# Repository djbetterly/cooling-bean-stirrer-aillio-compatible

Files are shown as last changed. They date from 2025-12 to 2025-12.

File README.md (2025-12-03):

# R1/R2 Cooling Bowl Stirrer (Aillio-Compatible)

<p align="center">
  
  
  
  <a href="https://github.com/djbetterly/cooling-bean-stirrer-aillio-compatible/releases">
    
  </a>
  <a href="https://github.com/djbetterly/cooling-bean-stirrer-aillio-compatible">
    
  </a>
</p>

### Open Hardware Release • Designed by Dustin Betterly



This **cooling bowl stirrer** is an open-hardware accessory **designed for compatibility with the Aillio R1 and R2 cooling bowls**.
It is **not affiliated with or endorsed by Aillio**.

Its purpose is simple: **speed up the cooling cycle and help remove any chaff that didn’t escape during roasting.**

By actively agitating the beans during cooling, the stirrer:

* Accelerates heat dissipation
* Improves airflow through the bean mass
* Breaks up clumps for more uniform cooling
* Helps eject additional trapped chaff
* Reduces total cooling time compared to passive airflow alone

**This tool is for post-roast cooling only.
It is NOT designed for use inside the roasting drum.**

---

## ✨ Features

* Rapid bean agitation for faster, more uniform cooling
* Helps remove residual chaff that didn’t exit the drum
* High-temperature stir paddle (PA6-CF recommended)
* Wear-friendly PTFE washer system
* Completely printable housing, paddle, and thumb screws
* Tested for safe use with hot roasted beans
* Open hardware — remix, improve, share

---

## 📦 Repository Contents

### /STL

* 3D Print - Bean Stirrer.stl
* 3D Print - Bottom Wear Plate.stl
* 3D Print - Top Wear Plate.stl
* 3D Print Axel Hub.stl
* 3D Print M5 Thumb Screw.stl
* 3D Print Motor Body Base.stl
* 3D Print Motor Body Wire Cover.stl
* Motor Body Cover.stl

### /docs

* bean_stir_manual.pdf
* Exploded_View.pdf

### /images

* hero_render.png

Other:

* README.md
* LICENSE (CC BY-NC 4.0)

---

## 🧰 Bill of Materials (BOM)

See:

* docs/Exploded_View.pdf

Key hardware:

* 80 mm stainless square rod (cut to length)
* PTFE shoulder washers
* Heat-set inserts
* Assorted M3/M5 fasteners
* 12 V DC motor (reverse-rotation supported)

---

## 🛠 Material Recommendations

| Part | Material | Brand | Notes |
| --- | --- | --- | --- |
| Stir Paddle | PA6-CF | Polymaker Fiberon | High heat deflection so hot beans won’t deform the paddle |
| Wear Plates | PA6-CF | Polymaker Fiberon | Low friction and heat resistant |
| Housing/Covers | PLA-CF | Bambu Labs | Rigid, stable, clean finish |
| Thumb Screws | PLA-CF | Bambu Labs | Strong and easy to bond to steel screws |

---

## 🪚 Cutting the Square Rod (80 mm)

The stainless square bar must be cut to **80 mm** final length.

Steps:

1. Mark 80 mm with calipers or a precise ruler
2. Cut using a hacksaw, bandsaw, or cutoff wheel
3. Deburr both ends with a file or sandpaper
4. Verify a smooth sliding fit into the printed hubs
5. Target tolerance: **80 ± 0.25 mm**

---

## 🖨 Printing Guidance

### Stir Paddle (PA6-CF)

* Print upside-down
* Supports: build plate only
* Add a pause to insert the embedded nut
* Optional: resin coat + sand for smoother finish

### Thumb Screws

* Pause print to insert the M5 screw
* Secure using resin or cyanoacrylate

---

## 🔧 Assembly Overview

See:

* docs/Aillio_Stirrer_Manual_FINAL_NEW_EXPLODED.pdf
* docs/Exploded_View.pdf

General notes:

* Center the stir paddle on the cooling bowl’s middle pin
* Do **not** overtighten the paddle screw — it must rotate freely
* Leave motor screws slightly loose during alignment
* Apply blue Loctite after the final position is confirmed

---

## ⚡ Motor & Power

* Uses a 12 V DC motor
* If the paddle spins backward → swap + and – wires
* Recommended power supply: **12 V / 2 A**

---

## 🛡 License — CC BY-NC 4.0

This project is released under a **Creative Commons Attribution-NonCommercial 4.0 International License**.

You may:

* Print and remix for personal use
* Share non-commercially
* Must credit: **Dustin Betterly**

You may NOT:

* Sell the files
* Sell printed parts or kits
* Use commercially without permission

Full license text:
[https://creativecommons.org/licenses/by-nc/4.0/](https://creativecommons.org/licenses/by-nc/4.0/)

---

## 🙌 Credits

**Design & documentation:**
Dustin Betterly

**Render:**
images/hero_render.png

---

## 🗂 Version History

### v1.0 — Initial Public Release

* Finalized STL files
* Updated exploded view
* Complete build manual
* Updated naming for trademark safety
* CC BY-NC license applied

> If you build it, share your results!
> Pull requests, improvements, and remixes are welcome (non-commercial only).

---

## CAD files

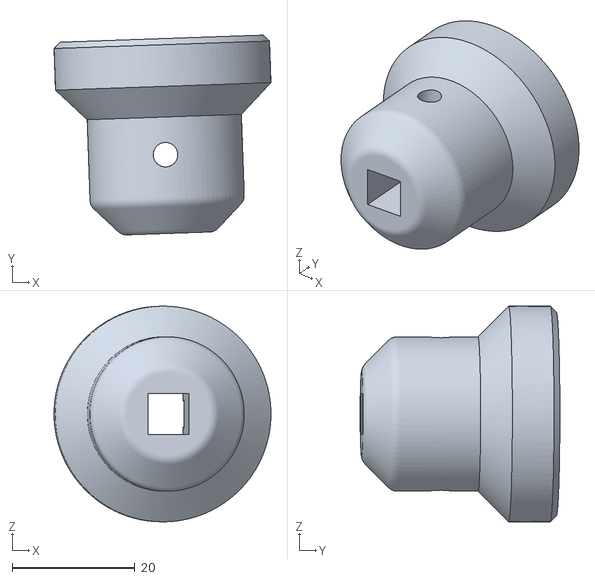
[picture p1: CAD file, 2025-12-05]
STL/3D Print Axel Hub.stl
35.4 x 32.6 x 35.2

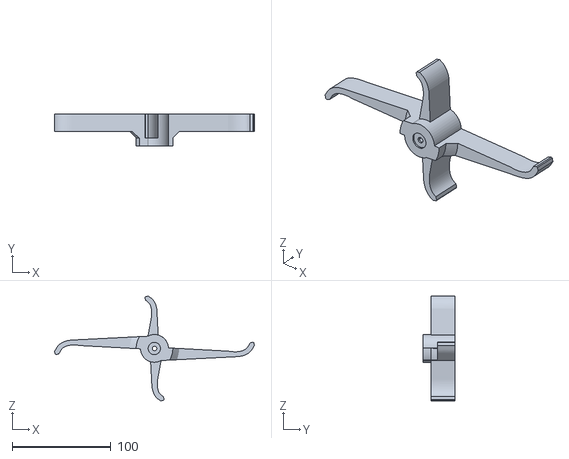
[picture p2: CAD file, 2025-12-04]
STL/3D Print - Bean Stirrer.stl
202.5 x 32.7 x 106.1

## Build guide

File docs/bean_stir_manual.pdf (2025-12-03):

## Designed by Dustin Betterly

### Includes Build Notes, License, and Exploded Technical Drawing

# R1/R2 Bean Stirrer

## (Aillio Compatible)

# Open Hardware Release Manual

# Disclaimer

This project is provided as open hardware for community use. No warranty of any kind is provided. Use, modification, and assembly of this project are at your own risk. By using these files, you agree that: -You are responsible for safe printing, assembly, and operation. - You assume all risks associated with mechanical, electrical, or thermal failure. - The designer is not liable for damages, injury, or loss. These notes provide high-level guidance only and are not step-by-step instructions.

# License - CC BY-NC 4.0

This project is released under the Creative Commons Attribution-NonCommercial 4.0 License. You may: - Print, remix, and adapt the files. - Share them for non-commercial use. - Must credit the original designer: Dustin Betterly. You may NOT: - Sell the files or derivatives. - Sell printed parts or kits. - Use

### this design commercially without permission. Full license: https://creativecommons.org/licenses/by-nc/4.0/

# Build Notes

# 3D Printed Parts & Materials

(Your original table with brands, links, and materials should remain exactly as-is below this text.)

The materials were selected to balance durability, printability, and performance in a high-heat environment.

## - Polymaker Fiberon PA6-CF was chosen for the stirrer paddle and wear plates because of its high heat deflection temperature, ensuring that hot roasted beans won’t soften

or deform the stirrer.

## - Bambu Labs PLA-CF was used for structural parts such as the motor housing and

covers due to its stiffness, clean surface finish, and dimensional stability.

These combinations provide excellent strength and durability while maintaining reliability around elevated temperatures.

Motor Body | Bambu Labs PLA-CF
Bean Stirrer | Polymaker Fiberon PA6-CF (https://www.amazon.com/dp/B0D4QDTHPQ?ref_=ppx_hzsearch_conn_dt_b_fed_asin_title_1&th=1)
Axel Hub | Bambu Labs PLA-CF
Top Wear Plate | Polymaker Fiberon PA6-CF (https://www.amazon.com/dp/B0D4QDTHPQ?ref_=ppx_hzsearch_conn_dt_b_fed_asin_title_1&th=1)
Bottom Wear Plate | Polymaker Fiberon PA6-CF (https://www.amazon.com/dp/B0D4QDTHPQ?ref_=ppx_hzsearch_conn_dt_b_fed_asin_title_1&th=1)
M5 Thumb Screw | Bambu Labs PLA-CF
Motor Body Cover | Bambu Labs PLA-CF
Motor Body Wire Cover | Bambu Labs PLA-CF

These notes cover recommended materials, printing considerations, and general guidance for assembling and using the Aillio Bean Stirrer. This is not a step-by-step assembly guide. Use the exploded view drawing for part orientation and placement.

# Part Preparation

## Stir Paddle

After printing the paddle, I applied three coats of art resin, then sanded and polished the surface. This step is optional, but it improves smoothness and overall durability.

## Be careful not to let resin enter:

## - the bottom screw hole

## - the square axle hole

Both must remain clean for proper assembly.

## M5 Thumb Screws

## After printing the thumb screw bodies:

1. Thread the M5 screw into the printed body as far as it will go.
2. Secure it using either superglue or a small amount of art resin in the cavity.

Resin creates a permanent bond once cured.

## Cutting the Square Rod (Stainless Bar, Item 17)

The stainless steel square rod (Item 17 in the exploded view) must be cut to a final working length of 80 mm before assembly.

## Recommended cutting steps:

1. Measure and mark 80 mm from one end using calipers or a precision ruler.

## 2. Use a fine-tooth hacksaw, rotary tool with cutoff wheel, or metal bandsaw to make the

cut.

3. Deburr both ends with a file or sandpaper (120–220 grit) to remove sharp edges.
4. Ensure the rod slides cleanly into the printed hub and coupler without binding.

## 5. Confirm final length is 80 ± 0.25 mm (slight variance is acceptable)

## Printing the Stir Paddle (Embedded Nut)

## The paddle includes an embedded locking nut. For best results:

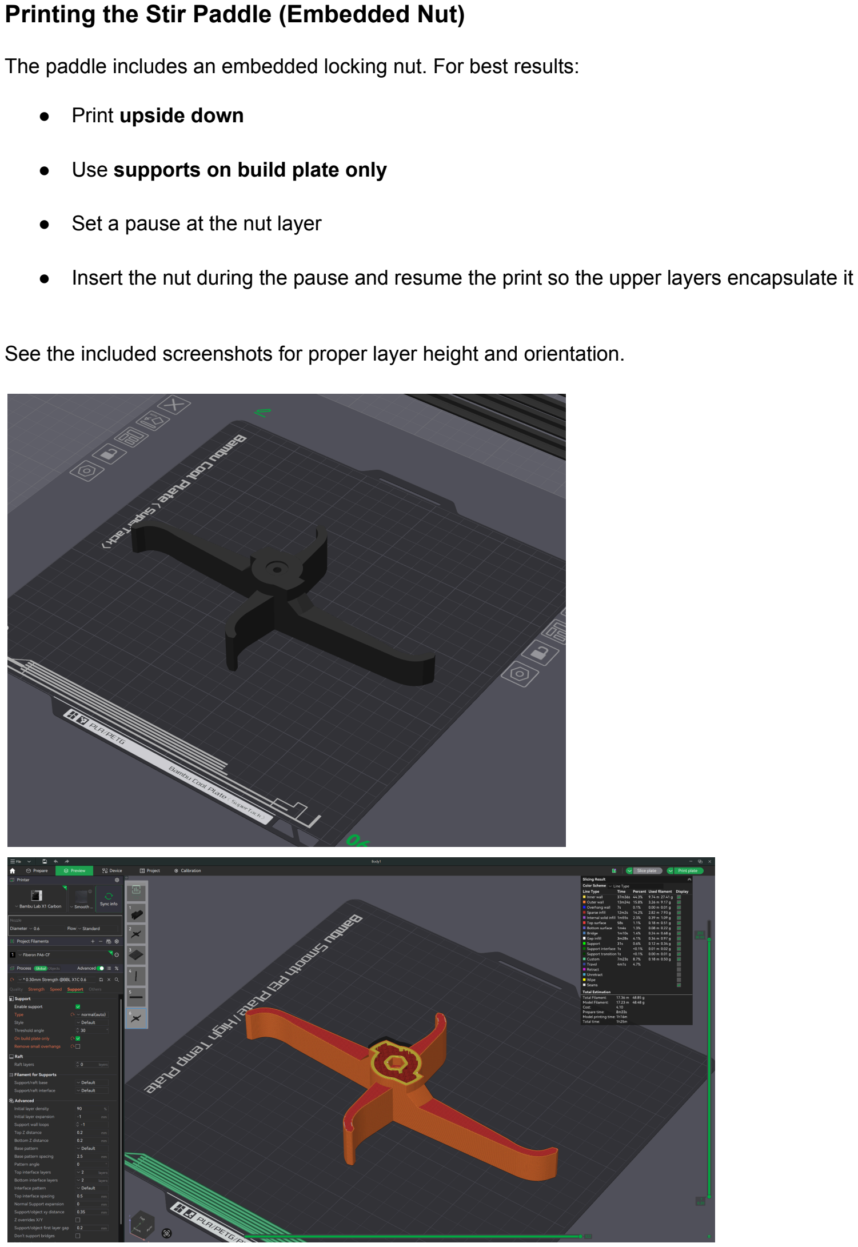
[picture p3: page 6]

## - Print upside down

## - Use supports on build plate only

## - Set a pause at the nut layer

## - Insert the nut during the pause and resume the print so the upper layers encapsulate it

See the included screenshots for proper layer height and orientation.

# Assembly Guidance

Use the exploded view drawing to identify part placement and orientation.

## When mounting the motor:

## - Leave the motor screws slightly loose during initial alignment—this helps reduce

vibration.

## - Once aligned, apply a small amount of blue Loctite to prevent the screws from backing

out during use.

## The goal is “secure but not stressed.”

# Installing the Stir Paddle in the Aillio Basket

The stirrer assembly includes several components. Carefully reference the exploded view to confirm the correct stack and alignment.

There is a small hole at the very center of the basket—this is where the stir bar must align. Do not overtighten the screw: the stir bar should rotate freely but without wobble.

A close-up diagram is included to assist with visual orientation.

# Wiring & Power Supply

The motor referenced in the BOM/exploded view is a reverse-rotation motor.

## If the paddle spins in the wrong direction:

- Reverse the positive and negative wires at the barrel connector.
This is safe and supported by the motor’s specifications.

A standard 12V / 2A power supply works well. (https://www.amazon.com/dp/B0D269PYK9?ref_=ppx_hzsearch_conn_dt_b_fed_asin_title_2)
Ensure the barrel connector matches both the motor and your chosen receptacle.

# Parts Wear & Long-Term Use

## This design has been tested for several weeks, but long-term wear may vary depending on

materials, roasting temperature, and usage frequency.

The white PTFE washers are designed to be the sacrificial wear components.
With the recommended materials, overall longevity should be good, though individual results may vary.

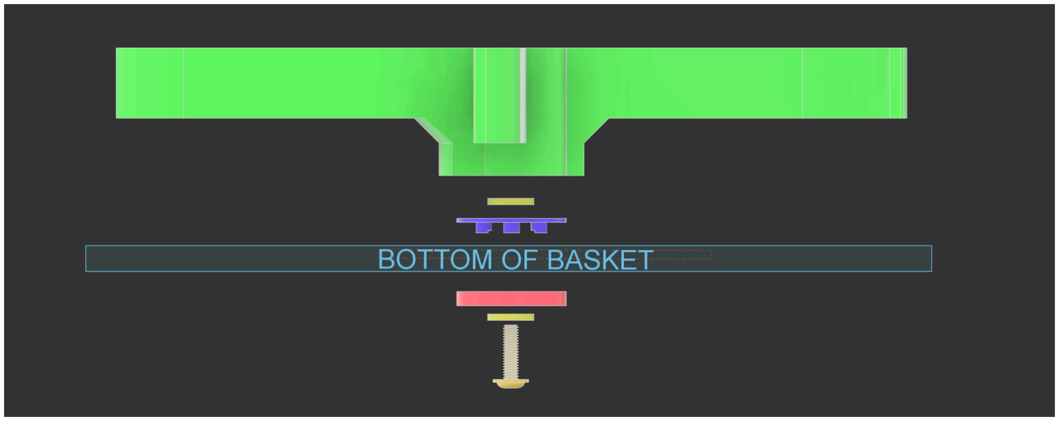
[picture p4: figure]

## Parts List

Item | Qty | Part Number | Material 1 | 1 | 3D Print - Bean

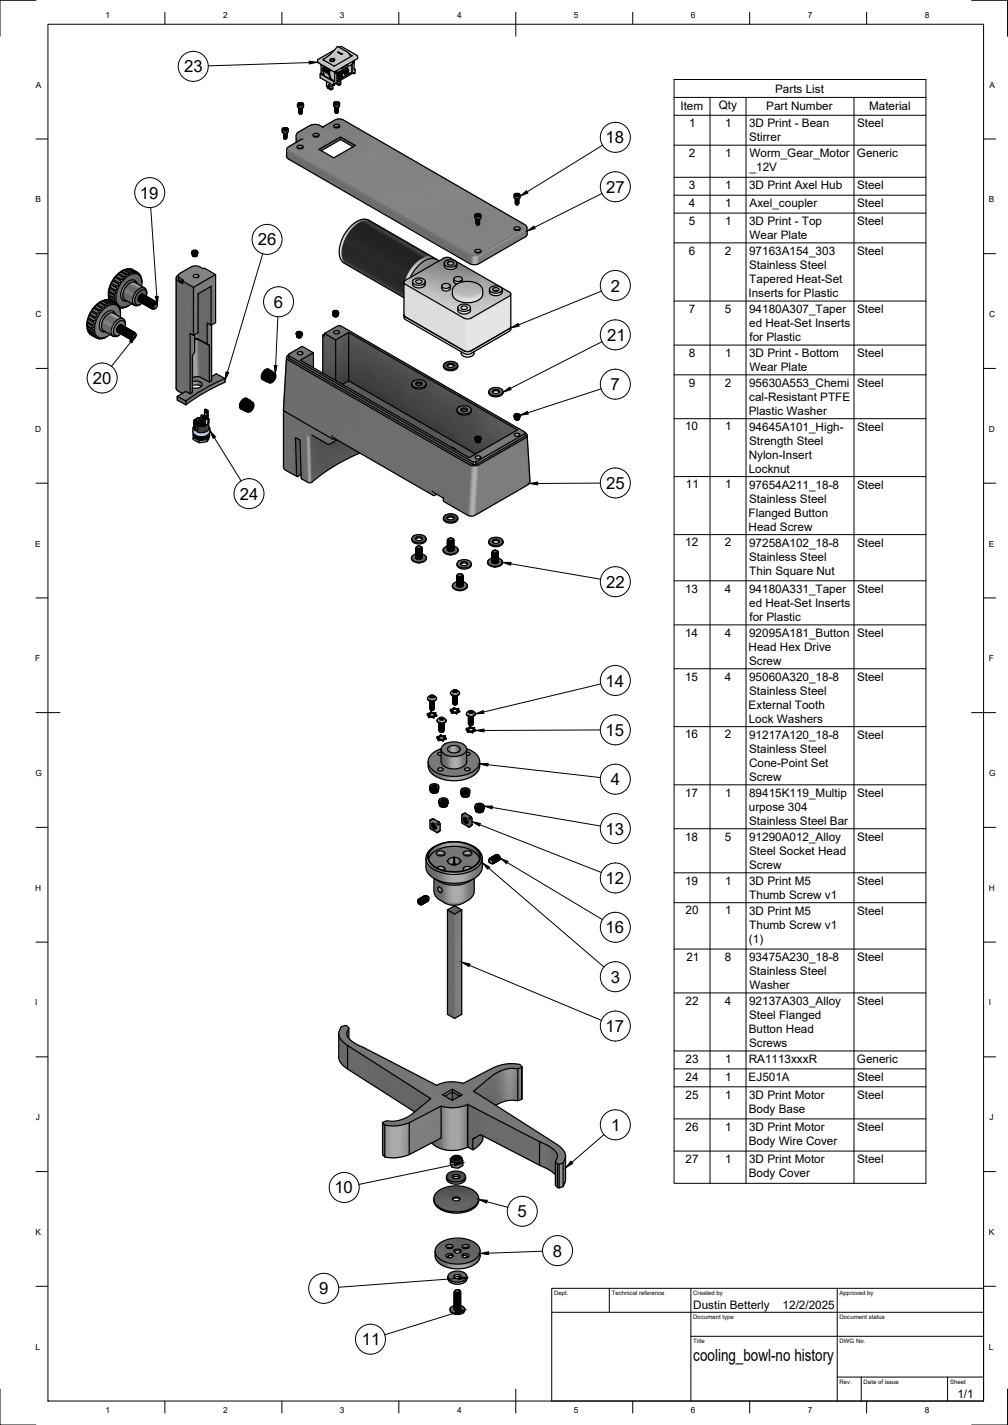
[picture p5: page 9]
8 ABCDEFGHIJKL; ABCDEFGHIJKL; Dept.; Technical reference; Created by; Approved by; Document type; Document status; Title; DWG No.; Rev.; Date of issue; Sheet; cooling_bowl-no history; Dustin Betterly; Stirrer; Steel 2; Worm_Gear_Motor; Generic 3; 3D Print Axel Hub; Steel 4; Axel_coupler; Steel 5; 3D Print - Top; Wear Plate; Steel 6; Steel 7; 94180A307_Taper; Steel 8; 3D Print - Bottom; Steel 9; 95630A553_Chemi; Steel; 94645A101_High-; Strength Steel Nylon-Insert Locknut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

Stainless Steel
Tapered Heat-Set
Inserts for Plastic

ed Heat-Set Inserts
for Plastic

cal-Resistant PTFE
Plastic Washer

Thin Square Nut

Head Hex Drive
Screw

Cone-Point Set

urpose 304
Stainless Steel Bar

Steel Socket Head

Body Wire Cover

R1/R2 Bean Stirrer
BOM
12/03/2025
Qty Part Number | Part Name | Vendor | External Link
1 3D Print - Bean Stirrer | 3D Print - Bean Stirrer | 3D Print | https://github.com/djbetterly/cooling-bean-stirrer-aillio-compatible/blob/main/STL/3D%20Print%20-%20Bean%20Stirrer.stl
1 3D Print - Bottom Wear Plate | 3D Print - Bottom Wear Plate | 3D Print | https://github.com/djbetterly/cooling-bean-stirrer-aillio-compatible/blob/main/STL/3D%20Print%20-%20Bottom%20Wear%20Plate.stl
1 3D Print - Top Wear Plate | 3D Print - Top Wear Plate | 3D Print | https://github.com/djbetterly/cooling-bean-stirrer-aillio-compatible/blob/main/STL/3D%20Print%20-%20Top%20Wear%20Plate.stl
2 3D Print M5 Thumb Screw | 3D Print M5 Thumb Screw | 3D Print | https://github.com/djbetterly/cooling-bean-stirrer-aillio-compatible/blob/main/STL/3D%20Print%20M5%20Thumb%20Screw.stl
1 3D Print Motor Body Base | 3D Print Motor Body Base | 3D Print | https://github.com/djbetterly/cooling-bean-stirrer-aillio-compatible/blob/main/STL/3D%20Print%20Motor%20Body%20Base.stl
1 3D Print Motor Body Cover | 3D Print Motor Body Cover | 3D Print | https://github.com/djbetterly/cooling-bean-stirrer-aillio-compatible/blob/main/STL/Motor%20Body%20Cover.stl
1 3D Print Motor Body Wire Cover | 3D Print Motor Body Wire Cover | 3D Print | https://github.com/djbetterly/cooling-bean-stirrer-aillio-compatible/blob/main/STL/3D%20Print%20Motor%20Body%20Wire%20Cover.stl
1 3D Print Axel Hub | 3D Print Axel Hub | 3D Print | https://github.com/djbetterly/cooling-bean-stirrer-aillio-compatible/blob/main/STL/3D%20Print%20Axel%20Hub.stl
1 Worm_Gear_Motor_12V | Worm_Gear_Motor_12V_27RPM | Amazon | https://www.amazon.com/dp/B07F8Q73VC?ref_=ppx_hzsearch_conn_dt_b_fed_asin_title_2&th=1
1 Toggle Switch 13mmx19mm | Toggle Switch 13mmx19mm | Amazon | https://www.amazon.com/TWTADE-Rocker-Switch-Position-KCD1-1-101/dp/B0CVTRKJTV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
1 | DC Power Supply Jack | DC Power Supply Jack Socket Female Panel Mount Connector 3-Pin 5.5 x 2.1mmAmazon | https://www.amazon.com/HiLetgo-Supply-Socket-Female-Connector/dp/B07XCNSM81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
1 | axel_coupler | axel_coupler | Amazon | https://www.amazon.com/dp/B0CSVZQHZY?ref_=ppx_hzsearch_conn_dt_b_fed_asin_title_1&th=1
1 | Power Supply | 12v 2amp Power Supply | Amazon | https://www.amazon.com/dp/B0D269PYK9?ref_=ppx_hzsearch_conn_dt_b_fed_asin_title_2
1 | 97654A211 | 18-8 Stainless Steel Flanged Button Head Screw | McMaster | https://www.mcmaster.com/97654A211/
1 | 94645A101 | High-Strength Steel Nylon-Insert Locknut (1) | McMaster | https://www.mcmaster.com/94645A101/
2 | 97163A154 | 303 Stainless Steel Tapered Heat-Set Inserts for Plastic | McMaster | https://www.mcmaster.com/97163A154/
5 | 94180A307 | Tapered Heat-Set Inserts for Plastic | McMaster | https://www.mcmaster.com/94180A307/
2 | 95630A553 | Chemical-Resistant PTFE Plastic Washer | McMaster | https://www.mcmaster.com/95630A553/
4 | 92137A303 | Alloy Steel Flanged Button Head Screws | McMaster | https://www.mcmaster.com/92137A303/
4 | 94180A331 | Tapered Heat-Set Inserts for Plastic | McMaster | https://www.mcmaster.com/94180A331/
8 | 93475A230 | 18-8 Stainless Steel Washer | McMaster | https://www.mcmaster.com/93475A230/
5 | 91290A012 | Alloy Steel Socket Head Screw | McMaster | https://www.mcmaster.com/91290A012/
2 | 91217A120 | 18-8 Stainless Steel Cone-Point Set Screw | McMaster | https://www.mcmaster.com/91217A120/
4 | 95060A320 | 18-8 Stainless Steel External Tooth Lock Washers | McMaster | https://www.mcmaster.com/95060A320/
4 | 92095A181 | Button Head Hex Drive Screw | McMaster | https://www.mcmaster.com/92095A181/
2 | 97258A102 | 18-8 Stainless Steel Thin Square Nut | McMaster | https://www.mcmaster.com/97258A102/
1 | 89415K119 | 6" Multipurpose 304 Stainless Steel Bar (80mm Final Size) | McMaster | https://www.mcmaster.com/89415K11-89415K119/
2 | 93070A125 | Alloy Steel Low-Profile Socket Head Screw | McMaster | https://www.mcmaster.com/93070A125/
